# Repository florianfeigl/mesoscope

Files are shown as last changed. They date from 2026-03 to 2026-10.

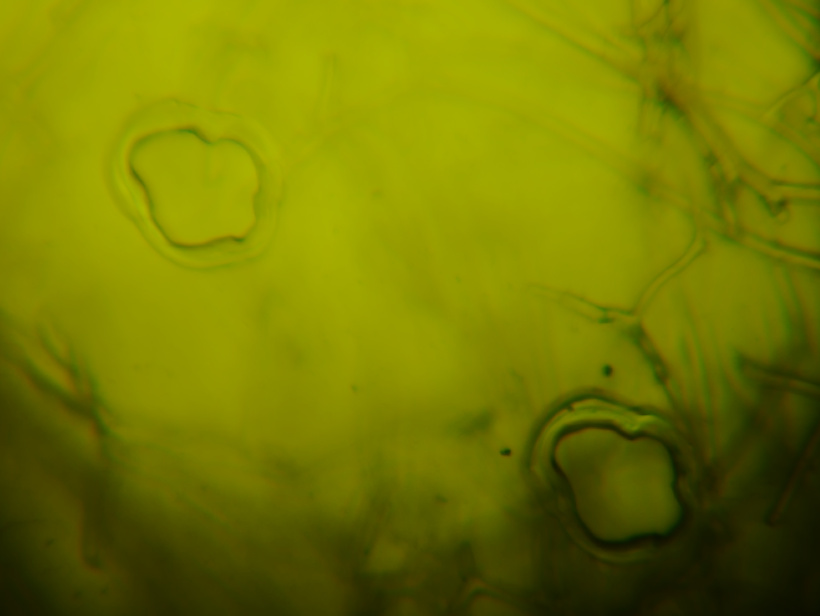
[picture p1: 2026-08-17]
resources/OFM_2026-08-17T13_33_07.449Z.jpeg

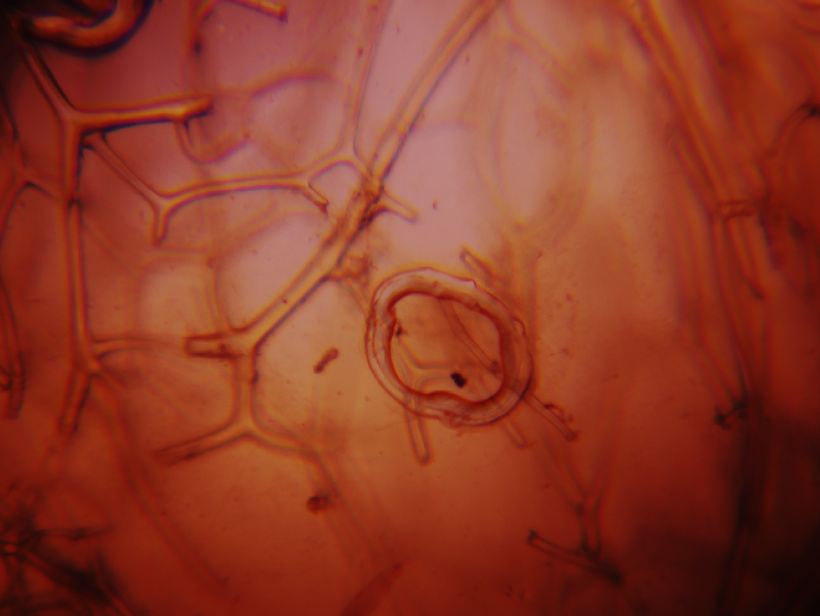
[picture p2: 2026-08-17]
resources/OFM_2026-08-17T14_42_57.477Z.jpeg

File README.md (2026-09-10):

# Mesoscope — IDANA

**IDANA** is the mesoscope model built in this project: an automated cell-imaging
microscope (Raspberry Pi 5 + Hailo-8 NPU + HQ Camera, OpenFlexure stack).
*Formerly "CELLAIR".*

## Roadmap

### Phase 1: Infrastructure & Base Setup
- [x] **Hardware Setup (Raspberry Pi 5)**
    - [x] Install Raspberry Pi OS (Trixie, Python 3.13)
    - [x] Configure AI HAT (26 TOPS) drivers and dependencies
    - [x] Configure Pi HQ Camera (IMX477) integration
    - [ ] Configure RTC Module (DS3231) -- hardware not yet connected
- [x] **Ansible Configuration**
    - [x] Create Ansible Playbook/Role for base system setup
    - [x] Create Ansible Role for AI HAT & Camera (`rpicam-apps`, `hailo-all`, `python3-picamera2`)
    - [x] Create Ansible Role for OpenFlexure dependencies

### Phase 2: Application Layer (OpenFlexure Porting)
- [x] Port OpenFlexure Server (v3, 3.0.0-alpha4) to RPi5/Trixie (Python 3.13)
    - [x] Switch from legacy `master` branch (Python 3.7/Flask) to `v3` branch (Python >= 3.11/FastAPI)
    - [x] Resolve build dependencies (`libcap-dev`, `rpicam-apps` replacing `libcamera-apps`)
    - [x] Deploy configuration (`ofm_config.json`) with HQ Camera and DummyStage
    - [x] Download and integrate web app frontend from GitLab CI artifacts
    - [x] Verify server starts, web UI accessible on port 5000
- [x] Fix Pi 5 pisp ISP compatibility (vc4 tuning files incompatible with Pi 5 ISP)
- [x] Fix pipewire camera device conflict (pipewire holds /dev/media* preventing picamera2 access)
- [x] Fix systemd SupplementaryGroups for camera access (video, render)
- [x] Fix DKMS kernel module build ordering (reboot between apt upgrade and modprobe)
- [x] Fix camera black frame issue (manual exposure via API: 20 ms / gain 1.5 / colour gains 1.4,2.3)
- [ ] Create software list for OpenFlexure Suite
- [ ] Validate Autofocus with motorised stage

### Phase 3: HQ Camera (IMX477) Integration
> **Note:** The primary microscope camera is the Pi HQ Camera (IMX477, C-mount).
> OpenFlexure v3 supports the IMX477 natively via picamera2. A custom optics module
> with a 125-150mm tube lens is required to properly fill the larger IMX477 sensor
> (see `hardware/optics/OPTICS_MODULE.md`).

- [x] Deploy OpenFlexure with HQ Camera (IMX477) configuration
- [x] Test live preview via OpenFlexure web UI
- [x] Verify Hailo-8 NPU inference (see test results below)
- [x] Design and 3D-print custom optics module for IMX477 + 125-150mm tube lens (STLs generated)
- [ ] Assemble optics module with tube lens and IMX477
- [ ] Validate autofocus with motorised stage

### Phase 4: Integration Testing
- [x] **Hardware Verification**
    - [x] Hailo-8 AI Processor detected on PCIe (`lspci`)
    - [x] Pi HQ Camera (IMX477) detected: 4056x3040 @10fps / 2028x1520 @30fps
    - [x] I2C buses operational (bus 1, 6, 10, 13, 14)
    - [x] Hostname, timezone, NTP synchronization confirmed
- [x] **OpenFlexure Server**
    - [x] Server starts and responds on HTTP (port 5000)
    - [x] Web UI accessible
    - [x] HQ Camera (IMX477) initialised and streaming
    - [x] Fix camera black frame issue (manual exposure via API: 20 ms / gain 1.5 / colour gains 1.4,2.3)
    - [ ] Test stage control via sangaboard (if connected)
    - [ ] Verify smart scan and autofocus functionality
- [x] **AI Inference (Hailo-8 NPU)**
    - [x] Hailo-8 NPU firmware verified: v4.23.0, Hailo-8 architecture
    - [x] DKMS driver build automated in Ansible (`hailo_pci` kernel module)
    - [x] Hailo-8 NPU inference verified (YOLOv8s Pose, 91.5 inf/s, 10.9ms latency)
    - [x] Benchmark complete (see Inference Test Results section)
- [x] **System Stability (post-reboot verification 2026-03-04)**
    - [x] RTC (DS3231) keeps time across reboots (`hwclock -r` confirmed)
    - [x] Hailo PCIe driver loads automatically on boot (`hailo_pci` module, `/dev/hailo0`)
    - [x] OpenFlexure service starts on boot, camera streaming active
    - [x] HQ Camera (IMX477) detected after reboot
    - [x] Resource usage under load (see below)

#### Resource Profile (idle with camera streaming)
| Resource | Value |
|---|---|
| CPU | 4 cores, load avg 0.71 (OpenFlexure ~63% of one core) |
| RAM | 762 MB used / 15 GB total (5% utilisation) |
| Temperature | 48.3C |
| Disk | 11 GB used / 117 GB total (10%) |
| Swap | 0 B used |

### Phase 5: OpenFlexure Microscope Build

> **Optics design:** See [`hardware/optics/OPTICS_MODULE.md`](hardware/optics/OPTICS_MODULE.md)
> for the full optical calculation — tube lens selection, sensor-to-lens distance,
> C-mount offset, and printed module dimensions for the IMX477 + scraped ≤10x objective.

- [ ] **Hardware Procurement**
    - [x] Pi HQ Camera (IMX477, C-mount) -- acquired, currently mounted on conventional microscope
    - [x] Scraped objective ≤10x (finite conjugate 160 mm) -- sourced from existing microscopes
    - [x] Tube lens 125 mm + 150 mm achromatic doublet (12.7mm dia) — acquired 2026-06-20
    - [ ] Sangaboard v0.5 motor controller
    - [ ] 3x 28BYJ-48 stepper motors -- acquired
- [ ] **3D Printing**
    - [x] Verify objective type (160 mm finite conjugate) and parfocal distance (see OPTICS_MODULE.md)
    - [x] Clone OpenFlexure repo (`hq_camera` branch) and set `CAMERA = "picamera_hq"` + tube lens params
    - [x] Generate custom optics module STLs with OpenSCAD (125mm and 150mm variants)
    - [ ] Print all parts (see `hardware/PRINT_CHECKLIST.md`)
    - [ ] Assemble optics module with tube lens and IMX477
- [ ] **Assembly & Calibration**
    - [ ] Assemble OpenFlexure with HQ Camera + scraped objective
    - [ ] Integrate with Ansible-deployed software stack
    - [ ] Calibrate flat-field correction and lens shading
    - [ ] Test motorised stage control via OpenFlexure web UI

## Bill of Materials

### Computing & AI
| Component | Description | Est. Price | Status |
|---|---|---|---|
| Raspberry Pi 5 (8GB) | Main computing unit | ~80 EUR | Acquired |
| AI HAT+ (Hailo-8, 26 TOPS) | PCIe NPU for heavy inference (segmentation, YOLOv8) | ~70 EUR | Acquired |
| DS3231 RTC Module | Battery-backed real-time clock | ~5 EUR | Acquired |
| GPIO Stacking Header | Pass-through for RTC under AI HAT | ~3 EUR | Acquired |
| MicroSD Card (32GB+) | OS and software storage | ~10 EUR | Acquired |
| USB-C Power Supply (27W) | Official RPi5 PSU | ~15 EUR | Acquired |

### Optics & Microscopy
| Component | Description | Est. Price | Status |
|---|---|---|---|
| Pi HQ Camera (IMX477) | C-mount, 12.3 MP sensor -- **primary microscopy camera** | ~35 EUR | Acquired |
| Scraped ≤10x objective | Finite conjugate 160 mm, sourced from existing microscopes | ~0 EUR | Acquired |
| Tube lens (125 mm + 150 mm) | Achromatic doublet, 12.7 mm dia | ~15-80 EUR | **Acquired** |
| 20x RMS Plan Achromat (0.40 NA) | Cell tracking, movement patterns (~0.7 µm resolution) | ~25-80 EUR | Pending |
| 40x RMS Plan Achromat (0.65 NA) | Subcellular detail, calcification (optional) | ~25-80 EUR | Optional |

### Motorised Stage
| Component | Description | Est. Price | Status |
|---|---|---|---|
| Arduino Nano (ATmega328p) | Sangaboard-compatible controller (DIY workaround) | ~5 EUR | Pending |
| 3x ULN2003 Driver Boards | Unipolar stepper drivers (usually bundled with motors) | ~3 EUR | Pending |
| 3x 28BYJ-48 Stepper Motors | 5V unipolar geared steppers (OpenFlexure standard) | ~5 EUR | Acquired |
| Jumper Wires (19x) | Wiring between Nano and ULN2003 boards | ~3 EUR | Pending |
| USB Cable (Mini-B) | Power + serial between RPi5 and Arduino Nano | ~3 EUR | Pending |

> **Alternative:** Sangaboard v0.3 PCB (~30-40 EUR if available from OpenFlexure vendors).
> The DIY workaround uses the same firmware and is fully compatible.

### 3D Printed Parts
| Component | Description | Est. Price | Status |
|---|---|---|---|
| OpenFlexure Microscope Body | Main structure with flexure stage | ~5 EUR filament | Ready to print |
| Optics Module (HQ Camera, 150mm) | Holds objective + HQ Camera + 150mm tube lens | ~2 EUR filament | STL generated |
| Optics Module (HQ Camera, 125mm) | Holds objective + HQ Camera + 125mm tube lens | ~2 EUR filament | STL generated |
| Illumination Module | LED illumination (transmission) | ~2 EUR filament | Ready to print |

### Consumables & Misc
| Component | Description | Est. Price | Status |
|---|---|---|---|
| M3 Screws/Nuts (assorted) | Assembly hardware | ~5 EUR | Pending |
| LED + Resistor | Sample illumination | ~2 EUR | Pending |
| Viton O-rings | Flexure preload (check OpenFlexure BOM) | ~3 EUR | Pending |

> **Estimated total (remaining):** ~110-170 EUR (depending on objective choice)

### Phase 6: Research & Experimentation
- [ ] **Incubator Setup (37C)**
    - [ ] Design separation of computing unit (outside) and camera (inside)
    - [ ] Inverted geometry: objective below, sample on top (OpenFlexure default)
- [ ] **Experiments**
    - [ ] Acquire PFA-fixed chip preparations
    - [ ] Analyze significant movement pattern changes in cells during calcification
    - [ ] Investigate influence of pressure changes on calcification [in progress]
    - [ ] Test series: Test different medium flow rates [in progress]

## System Architecture

```
                              MESOSCOPE SYSTEM
═══════════════════════════════════════════════════════════════════════════════

                    ┌─────────────────────────────────────┐
                    │         Raspberry Pi 5 (8GB)        │
                    │   ┌─────────────┐  ┌─────────────┐  │
                    │   │  OFM Server │  │ AI HAT+     │  │
                    │   │   (FastAPI) │  │ Hailo-8     │  │
                    │   └─────────────┘  │ 26 TOPS     │  │
                    │                    └─────────────┘  │
                    └──────────────┬──────────────────────┘
                                   │ CSI
                    ┌──────────────▼──────────────────────┐
                    │      HQ Camera (IMX477, 12MP)       │
                    │      C-Mount │ 150mm Achromat       │
                    │      10x/0.25 Objektiv              │
                    └──────────────┬──────────────────────┘
                                   │
                    ┌──────────────▼──────────────────────┐
                    │     OpenFlexure Microscope Body     │
                    │     Sangaboard v5 + 3× 28BYJ-48    │
                    │     XYZ-Flexure Stage               │
                    └──────────────┬──────────────────────┘
                                   │
                                   │  montiert auf Schlitten
                                   │
═══════════════════════╤═══════════▼══════╤══════════════════════════════════
  Linearschiene        │                  │
  ═════════════════════╪══════════════════╪═════════════════════════════════▶
                        │     ← →         │
                   Antrieb/Motor          │
═══════════════════════╧══════════════════╧══════════════════════════════════
          │                    │                    │
          ▼                    ▼                    ▼
   ┌─────────────┐      ┌─────────────┐      ┌─────────────┐
   │             │      │             │      │             │
   │ {Bioreaktor}│      │ {Bioreaktor}│      │ {Bioreaktor}│
   │             │      │             │      │             │
   │  hFOB 1.19  │      │  hFOB 1.19  │      │  hMEC 1    │
   │  + hMEC 1   │      │  + hMEC 1   │      │  (Kontrolle)│
   │             │      │             │      │             │
   └─────────────┘      └─────────────┘      └─────────────┘
         #1                   #2                   #n
```

Das Mikroskop fährt automatisch entlang der Schiene von Bioreaktor zu Bioreaktor,
nimmt Bilder auf, und der Hailo-8 läuft on-device Inferenz (Zellzählung,
Konfluenz, Segmentierung) — ohne externe Recheninfrastruktur.

> **Nächster Meilenstein — Halterung/Schiene:** Der mechanische Aufbau (Mikroskop
> um 90° gekippt auf X-Linearschiene + Reaktor-Gerüst in Serie) ist als Konzept in
> [`docs/RAIL_MOUNT_CONCEPT.md`](docs/RAIL_MOUNT_CONCEPT.md) festgehalten
> (Geometrie, Schienen-/Antriebsempfehlung, Flexure-Schwerkraftrisiko, offene Punkte).

### HQ Camera (IMX477) -- Microscopy

The Pi HQ Camera with C-mount and RMS objectives provides cell-level resolution:

| Objective | Resolution | Use Case |
|---|---|---|
| ≤10x / ≤0.25 NA | ~1.3 µm | Overview, colony counting |
| 20x / 0.40 NA | ~0.7 µm | Cell tracking, movement patterns |
| 40x / 0.65 NA | ~0.4 µm | Subcellular detail, calcification |

The custom 125-150mm tube lens (vs. standard 50mm) fills the larger IMX477 sensor
(7.86×5.89 mm vs. 3.68×2.76 mm for Pi Camera v2), achieving ~85-95% sensor utilization.
See [`hardware/optics/OPTICS_MODULE.md`](hardware/optics/OPTICS_MODULE.md) for details.

### Hailo-8 NPU -- Inference

The Hailo-8 AI HAT runs compiled HEF models for real-time cell segmentation at the microscope:

- **YOLOv8s-seg**: Cell segmentation (osteoblast, epithelial, calcium classes)
- **ByteTrack**: Cell tracking for migration velocity and calcium proximity analysis
- **Throughput**: 91.5 inf/s at 10.9ms latency (YOLOv8s Pose benchmark)

## Post-Deployment Verification

Run the following after a fresh boot to verify all subsystems:

```bash
# System basics
hostname && timedatectl

# RTC
sudo hwclock -r

# I2C - RTC at 0x68
sudo i2cdetect -y 1

# Hailo NPU
lsmod | grep hailo
ls /dev/hailo*
hailortcli fw-control identify

# Camera (HQ Camera IMX477)
rpicam-hello --list-cameras

# OpenFlexure
sudo systemctl status openflexure

# HTTP
curl -s http://localhost:5000/ | head -5
```

### Expected Results
| Check | Expected |
|---|---|
| Hostname | `mesoscope` |
| Timezone | `Europe/Berlin`, NTP synced |
| RTC | Current time, matches system clock |
| I2C bus 1 | `UU` at address `0x68` (DS3231) |
| Hailo module | `hailo_pci` loaded, `/dev/hailo0` present |
| Hailo firmware | v4.23.0, Hailo-8 architecture |
| Camera | `imx477` detected, 4056x3040 / 2028x1520 |
| OpenFlexure | `active (running)`, enabled on boot |
| HTTP | HTML response on port 5000 |

## Deployment

### Prerequisites (Client Side)
- **Ansible** (>= 2.10)
- **Python 3**
- **SSH Client** (e.g., OpenSSH)
- **Git**

### Target System Defaults
| Component | Value |
|---|---|
| Hostname | `mesoscope` |
| Provision User  | `lab` |
| OS | Raspberry Pi OS (Trixie) |
| Python | 3.13 |
| Hardware | RPi5, AI HAT 26 TOPS, HQ Camera IMX477 |

### Step 1: Flash the SD Card
1. Download and install [Raspberry Pi Imager](https://www.raspberrypi.com/software/).
2. Select **Raspberry Pi OS (64-bit, Trixie)** as the operating system.
3. Click the **settings icon** (gear) and configure:
   - **Hostname:** `mesoscope`
   - **Username:** `lab`
   - **Password:** (choose a secure password)
   - **Enable SSH:** select "Allow public-key authentication only" and paste your public key (e.g., contents of `~/.ssh/id_ed25519.pub`)
   - **Timezone:** `Europe/Berlin`
   - **WiFi:** configure if not using Ethernet
4. Flash the SD card and insert it into the Raspberry Pi 5.

### Step 2: Verify SSH Connection
After the Pi has booted (allow ~1-2 minutes for first boot):
```bash
ssh lab@mesoscope.local
```

### Step 3: Run the Ansible Playbook
```bash
git clone git@github.com:florianfeigl/mesoscope.git
cd mesoscope/ansible
ansible-playbook site.yml --skip-tags motor-controller -v -K
```

> **Note:** The `motor-controller` tag is skipped until Sangaboard hardware is connected.
> The playbook includes Pi 5 compatibility patches (pisp ISP tuning, pipewire masking, etc.)
> applied automatically via the `patch_rpi5_pisp.sh` script.

### Step 4: Verify
Access OpenFlexure at `http://mesoscope.local:5000/`

### Customization
To use different credentials, update the following files:
- `ansible/inventory/hosts.yml` -- hostname, IP, and SSH user
- `ansible/group_vars/all.yml` -- hostname and application user
- `ansible/ansible.cfg` -- default remote user

## AI Models

### Hailo-8 NPU Models

Pre-installed HEF models at `/usr/share/hailo-models/` (installed via `hailo-models`).
These run on the Hailo-8 NPU (AI HAT, 26 TOPS) via PCIe for real-time cell analysis.

| Model | Task | File |
|---|---|---|
| YOLOv8s Pose | Pose Estimation | `yolov8s_pose_h8.hef` |
| YOLOv5n Segmentation | Segmentation | `yolov5n_seg_h8.hef` |
| YOLOv5s PersonFace | Detection | `yolov5s_personface_h8l.hef` |
| SCRFD 2.5G | Face Detection | `scrfd_2.5g_h8l.hef` |

> See `ls /usr/share/hailo-models/` for the full list (18 models).
> The custom cellseg model (YOLOv8s-seg fine-tuned on osteoblast/epithelial/calcium classes)
> will be compiled to HEF and deployed at `model/models/compiled/cellseg.hef`.

## Inference Test Results

### Hailo-8 NPU via PCIe (tested 2026-03-03)
```
Firmware: v4.23.0 (release, app, extended context switch buffer)
Device: /dev/hailo0 on PCIe bus 0001:01:00.0
Model: YOLOv8s Pose (yolov8s_pose_h8.hef)
Input: 640x640x3
Output: 9 tensors (multi-scale detection + keypoints)
Throughput: 91.5 inferences/sec
Latency: 10.9ms avg
```

### Architecture
```
HQ Camera (IMX477) --> picamera2 streams (OpenFlexure UI)
                         |
                         v
Captured Frame --> Hailo-8 NPU (PCIe, 26 TOPS) --> Output tensors
                    Heavy: segmentation, pose estimation, custom HEF models
## Notes
- **Meetings:** Jour fixe is usually Tuesday 10:00 AM.

### Suppliers
- Praxisdienst: [https://www.praxisdienst.com/de-de]
- FluidControl: [https://www.fluidcontrolproducts.com/]

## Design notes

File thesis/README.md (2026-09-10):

# Mesoscope — Master's Thesis (LaTeX)

IEEEtran journal-class draft of the mesoscope thesis. The scaffold and the
already-known content (introduction, background, requirements, optical,
mechanical, electronics, software, edge-AI, cost) are filled in; results that
depend on future experiments are marked inline as `[TODO: ...]` (red).

## Layout

| Path | Contents |
|---|---|
| `main.tex` | Preamble, title, abstract, `\input`s all sections, bibliography |
| `sections/01_introduction.tex` … `11_conclusion.tex` | Body chapters |
| `sections/A_appendix.tex` | Printed-parts table and wiring appendix |
| `references.bib` | BibTeX entries (OpenFlexure, UC2, Squid, Cellpose, StarDist) |
| `figures/` | Local figures (currently empty) |

Figures are also pulled from `../hardware/assembly/` via `\graphicspath`. The
exploded-view PNGs there are **not committed** — regenerate them first with
`hardware/assembly/build_exploded.sh` (the thesis uses
`exploded_view_nolabels.png`).

## Build

```bash
make            # pdflatex + bibtex + pdflatex x2  ->  main.pdf
make clean      # remove aux files
make distclean  # also remove main.pdf
```

Requires `pdflatex` and `bibtex` (TeX Live; `texlive-publishers` provides
`IEEEtran.cls`/`IEEEtran.bst`). `biber` is **not** needed. `latexmk` is
optional (`make watch`).

## Status

Draft (milestone M0). Open decisions and parameter gaps are flagged as
`[TODO: ...]` and cross-referenced to `docs/THESIS_PARAMETER_GAPS.md` and the
milestones M1–M3.

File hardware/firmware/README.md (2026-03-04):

# Motor Controller Firmware

This directory contains the Sangaboard-compatible firmware for the Arduino Nano motor controller.

The firmware is automatically deployed via the `motor-controller` Ansible role.

**Source:** https://gitlab.com/openflexure/sangaboard/

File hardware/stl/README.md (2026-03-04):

# OpenFlexure Microscope STL Files

Download the STL files from the OpenFlexure v7 build server and place them in the appropriate subdirectories.

**Source:** https://build.openflexure.org/openflexure-microscope/v7.0.0-beta2/docs/high_res_microscope.html

## Directory Structure

```
stl/
  microscope-body/    Main body with flexure stage
  optics-module/      Camera + objective holder (HQ Camera variant)
  stage/              Sample stage and clips
  illumination/       LED illumination module and condenser
  motor-mounts/       Stepper motor mounting brackets
  tools/              Assembly jigs and alignment tools
```

## Print Settings (recommended)
- **Material:** PLA or PETG
- **Layer height:** 0.15-0.2mm
- **Infill:** 20-30%
- **Supports:** As indicated per part in OpenFlexure instructions
- **Nozzle:** 0.4mm

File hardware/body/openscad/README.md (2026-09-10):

# Mesoscope main body (Z-focus only)

OpenSCAD override of the OpenFlexure `main_body` for the rail mount
(`docs/RAIL_MOUNT_CONCEPT.md`). In the tilted setup the sample chips hang
externally from the bridge, so the microscope's own X/Y stage is never used.
This variant removes it.

## Files

| File | Purpose |
|---|---|
| `main_body_original.scad` | Byte-identical backup of upstream `openscad/main_body.scad` (hq_camera branch, commit `5e90e97`). |
| `main_body_structure_original.scad` | Byte-identical backup of upstream `openscad/libs/main_body_structure.scad`. |
| `main_body_mesoscope.scad` | Entry file (copied over `openscad/main_body.scad`). `VERSION_STRING = "Mesoscope"`. |
| `main_body_structure_mesoscope.scad` | Upstream structure lib + a mesoscope `main_body()` at the bottom. All upstream modules are kept unchanged so the rendering scenes still work. |
| `build_body.sh` | Copies the overrides into the upstream clone and renders. |

## What was removed vs. upstream

- `xy_stage_with_nut_traps` — the sample stage (Tisch) incl. nut traps
- `xy_legs_and_actuators` — the four flexure legs, both X/Y actuator columns and their screw seats / motor lugs
- `xy_flexures`, `xy_leg_ties` — flexures and print ties
- `side_housing` — the two X/Y motor cable housings on the outer walls
- `xy_actuator_cut_outs` — no columns left to clear from the walls

## What is kept

- `complete_z_actuator` + `z_axis_casing` (focus, optics module mount, condenser/illumination dovetail mount)
- `internal_xy_structure` — inner wall + base with the central optics cut-out and the reflection-illuminator cut-out
- outer walls (`wall_inside/outside_xy_actuators`, `wall_between_actuators`) — where the actuator columns stood, a short straight wall segment (`mesoscope_actuator_stub_wall`) closes the gap
- `mounting_hole_lugs` — the four M3 base lugs (needed later for the rail carriage adapter)
- logos / version string on the outer walls

Removing the X/Y flexures also removes the X/Y gravity-sag risk of the tilted
microscope (RAIL_MOUNT_CONCEPT §5); only the Z flexure remains.

## Build

```bash
hardware/body/openscad/build_body.sh            # -> hardware/stl/models/main_body_mesoscope.stl
hardware/body/openscad/build_body.sh original   # -> hardware/stl/models/main_body_original.stl
hardware/body/openscad/build_body.sh all
```

Needs the upstream clone at `sources/openflexure-microscope` (same location
as `build_stand.sh`). After the run the upstream clone is left in the
*mesoscope* state, so `rendering/librender/rendered_main_body.scad` and the
full-microscope scenes (`hardware/mount/openscad/complete_microscope_*.scad`)
render the reduced body once `rendered_main_body.stl` is regenerated.

## Open points

- The Sangaboard stays for now (decision 2026-09-03); X/Y motor outputs are
  simply unused. `ofm_config.json.j2` still declares a 3-axis stage — OK for
  now, the X/Y axes just have nothing attached.
- Test print pending. Check that the stub walls and the front lugs print
  cleanly without the actuator columns behind them.

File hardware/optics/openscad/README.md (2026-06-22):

# Mesoscope HQ Camera Optics Module — OpenSCAD Sources

Custom OpenSCAD configurations for the Pi HQ Camera (IMX477) with extended tube
lens options (125mm and 150mm achromatic doublets).

## Files

| File | Purpose |
|---|---|
| `optics_configurations_hq.scad` | Tube lens configs: 125mm and 150mm |
| `rms_optics_module_hq.scad` | Main module with dispatch for all 6 optics types |
| `picamera_hq_cmount.scad` | **C-mount override** for upstream `picamera_hq.scad` — replaces bare-PCB mounting with a C-mount flange seat |
| `build_optics.sh` | Copies configs into upstream repo and builds STLs |

## Setup

```bash
# 1. Clone upstream repo (once):
cd ~/dev/mesoscope/sources
git clone --branch hq_camera --single-branch \
  https://gitlab.com/openflexure/openflexure-microscope.git
cd openflexure-microscope && git lfs install && git lfs pull

# 2. Build (the script copies custom files into the upstream repo automatically):
cd ~/dev/mesoscope/hardware/optics/openscad
./build_optics.sh
```

If the upstream repo is re-cloned, just re-run `./build_optics.sh` — it copies the custom files each time.

## Building STLs

```bash
./build_optics.sh          # Both configurations
./build_optics.sh 125      # 125mm only
./build_optics.sh 150      # 150mm only
```

Output: `../stl/models/optics_hq_125_rms.stl` and `optics_hq_150_rms.stl`

## Available Optics Configurations

| OPTICS name | Tube lens | f (mm) | ffd (mm) | Conjugate | Camera |
|---|---|---|---|---|---|
| `rms_f125d13` | 125mm | 125 | 122.6 | Finite | picamera_hq |
| `rms_f150d13` | 150mm | 150 | 146.9 | Finite | picamera_hq |
| `rms_infinity_f125d13` | 125mm | 125 | 122.6 | Infinity | picamera_hq |
| `rms_infinity_f150d13` | 150mm | 150 | 146.9 | Infinity | picamera_hq |

## Key Parameters (from OPTICS_MODULE.md)

| Parameter | 125mm | 150mm |
|---|---|---|
| Magnification (M) | 0.469 | 0.515 |
| Effective FN | 20.9 mm | 19.0 mm |
| Sensor fill | ~85% | ~95% |
| Lens-to-sensor (q) | 66.4 mm | 72.8 mm |

Use **150mm** for <=10x objectives (preferred).
Use **125mm** for <=4x objectives or wider field of view.

## Verifying tube_lens_ffd

Before printing, check your lens datasheet for the **back focal distance (BFD)**.
If it differs from the values below, edit `optics_configurations_hq.scad`:

| Lens | ffd | Source | Parameter |
|---|-----|---|---|
| 125mm | 124.1 mm | taulab supplier (Filip, 2026-06-22) | `rms_f125d13_config` |
| 150mm | 148.8 mm | taulab supplier (Filip, 2026-06-22) | `rms_f150d13_config` |

## C-mount camera-side interface

The mesoscope uses the Pi HQ Camera **intact** (with its C-mount body), not the
bare PCB. `picamera_hq_cmount.scad` overrides the upstream `picamera_hq.scad` so:

| Parameter | Upstream (bare PCB) | Mesoscope (C-mount) |
|---|---|---|
| `mount_height` | 4.5 mm | 17.526 mm (C-mount FFD) |
| `sensor_height` | 1 mm | 0 mm (referenced to flange face) |
| Camera mount | 4× M2 posts on a 30 mm pattern | Smooth bore + 32 mm flange seat |
| Camera screws | 4× No.2 self-tapping | None — not needed with C-mount |
| Cover STL | `picamera_hq_cover.stl` | None — camera body is its own enclosure |

The optics module has a **32.6 mm bore × 4 mm deep flange seat**; the
C-mount housing of the HQ Camera (32 mm OD) slides into it with ~0.3 mm
clearance. Above the seat, a **26 mm clear bore** lets the sensor see the tube
lens unobstructed. The sensor ends up exactly 17.526 mm below the printed seat
face — matching the C-mount standard.

We deliberately do **not** print 1"-32 UN female threads (FDM threads are
unreliable at this scale). The slip-fit is more than tight enough for an
inverted scope where the C-mount face seats against the printed lip under
gravity. If you mount the scope upright, add a small printed retainer or a
wrap of PTFE tape on the camera flange.

## Implementation note: sequential_hull fix

The OpenFlexure upstream `optics_module_rms()` uses `sequential_hull()` to build
the module body. This hull always **closes the underside** — regardless of what
`picamera_hq_camera_mount` subtracts internally. The C-mount opening is therefore
cut as a post-process in `rms_optics_module_hq.scad` via an explicit `difference()`
in `optics_module_rms_cmount()`:

- Flange seat (⌀32.6 mm, 4 mm deep) cut from `camera_mount_top_z` downward
- Clear optical bore (⌀26 mm) cut through the full remaining hull depth

`rms_camera_mount_top_z()` is `-33.8 mm` for the 150 mm config (computed from
sensor Z + C-mount FFD). The safety cutout extends 40 mm further down to punch
through any hull-generated floor.

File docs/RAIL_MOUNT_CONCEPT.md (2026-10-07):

# Rail Mount Concept — Tilted Microscope on Linear X-Rail

> **Status:** Concept + first schematic CAD draft (updated 2026-09-03 —
> motor-control architecture is now a **hybrid**: the Sangaboard stays for
> focus + illumination LED, the linear rail runs on a standalone TMC2209 at
> GPIO; this narrows the earlier 2026-09-02 "all-Python GPIO stage" to just the
> rail axis. See the decision box in §7.1; handoff list at the end of §8).
> Next milestone: the mount ("Halterung") that lays the mesoscope on its side
> and carries it along a linear X-rail past a series of bioreactors.
>
> **Schematic massing draft:** `hardware/mount/openscad/rail_mount_mesoscope.scad`
> (parametric block model — shared **base plate (Grundplatte)**, the rail beam +
> MGN12 guide under the moving microscope, NEMA17 + T8 leadscrew drive, and a
> **reactor bridge (Brücke)**: a continuous traverse board with per-station
> cutouts from which the chips hang **hochkant**). Previews:
> `rail_mount_preview.png` (3/4 from the objective side) and
> `rail_mount_top.png` (3/4 from the light-source side, full row). This is a
> massing model to make the layout discussable, **not** print-ready geometry.
>
> ✅ **Full mesoscope model embedded — registration CORRECTED (2026-08-25):**
> the real assembled geometry is `import()`ed into the draft
> (`real_model = true`) from `hardware/stl/models/complete_microscope_rms.stl`.
> The upstream render applies `rotate([-90,0,0])`, so in the STL the optical
> axis is the line `x=0, z=0` pointing **+Y** (objective toward the reactors).
> **Important correction:** the render scene includes the **stand**, which
> raises the microscope body frame by **75 mm** (`microscope_on_stand_pos`:
> lug_z 55 + lug 20). The sample plane therefore sits at **model y = 150**,
> *not* at `sample_z = 75` as previously assumed — that wrong registration
> placed the chip 75 mm *inside* the microscope and caused both rounds of
> visible clipping. Measured from the STL: **objective tip = y 146.65**
> (global foremost point, working distance 3.35 mm), condenser tip = y 167.5
> (17.5 mm above the sample plane — the earlier "2.5 mm" figure was an
> artifact of the wrong registration).
>
> ✅ **Illumination arm removed from the model (per decision):** the 16 mm chip
> would leave only ~1.5 mm nominal clearance under the stock condenser, and
> the illumination must be redesigned anyway for trans-illumination from
> behind the chip row. The model is now rendered **without sample clips AND
> without the illumination assembly** (dovetail, condenser, wiring):
> `hardware/mount/openscad/complete_microscope_rms_noclips_noillum.scad`, a
> variant of upstream `rendering/complete_microscope.scad` that re-composes
> `assembled_microscope_without_electronics` as motors +
> `mounted_microscope()` only. Copy into the upstream `rendering/` dir and
> render there to regenerate the STL. The custom light source ("Halterung
> unten") comes later as a separate part on the +Y side behind the chips.
>
> ✅ **10 mm working gap established (per decision):** the microscope is shifted
> back along the optical axis (`model_dy = (75 − 10) − 146.65 ≈ −81.7 mm`)
> so the objective tip stops **10 mm** before the chip window (world y = 65
> vs. window at y = 75). Since the tip is the model's foremost point, the
> **entire microscope stays at world y ≤ 65 at every rail position** —
> chips (y ≥ 75), traverse board (y ≥ 80) and pillars are cleared by
> construction; no separate travel-path check needed. **Optics consequence:**
> the stock focus plane lies 3.35 mm beyond the tip, so to focus at the chip
> window inner face the objective must protrude **~8 mm beyond stock** —
> more to reach deeper planes inside the 16 mm chip. This optics-module
> adaptation (longer nose/extension tube) is an accepted follow-up task.
>
> ✅ **Bridge clearance:** with the shifted microscope (everything ≤ y 65) the
> slim traverse board (24 mm, starting at y = 80, `bridge_y_clear = 5`) is
> trivially clear. The station cutouts are **front-open notches**: chips
> slide in from the objective side.
>
> ✅ **Bioreactor STL integrated:** `hardware/bioreactors/chip_senkrecht_mit_bodenplatte.stl`.
> Base plate (Bodenplatte) removed for the calculations per
> instruction → chip body **70 × 40 × 16 mm**, optical window **18 × 8 mm**,
> 4 fluidic ports. Only the **series pitch** (reactor-to-reactor spacing along
> X) is still an assumption (80 mm) to confirm.
>
> ✅ **Hochkant + Brücke (2026-08-25):** the chips are now mounted **upright
> (hochkant)** and **hang from a bridge** — a continuous traverse board
> ("schmales Brett" in chip dimensions) with per-station cutouts
> (Aussparungen), carried by two end pillars on the Grundplatte. Imaging goes
> horizontally **through the 16 mm chip thickness**: light source on the +Y
> side → chip → objective on the −Y side. The fluidic ports + tubes
> (Schläuche) exit at the **top** — that is why top access is impossible and
> the chips must hang, keeping the space **below** free for the moving
> mesoscope. Pillar clearance at the end stops is confirmed: microscope
> half-width 85 mm vs. `bridge_x_clear = 120 mm` → ≥ 35 mm margin; the
> travel path under the hanging row is clear (microscope ≤ y 65 everywhere).

This document captures the geometry, the mechanical concept, open decisions, and
the reasoning behind them, so the next session can start from a shared picture.

---

## 1. Goal

Transform the microscope from a static inverted instrument into a **moving
imaging head** that scans a **row of bioreactors** arranged in series:

- Lay the whole OpenFlexure microscope on its side (**90° tilt**), resting on the
  face of the **Z-axis motor**, so the **optical axis becomes horizontal**.
- Bind a **linear rail under the microscope** so it rides on a **carriage** in
  **X** (90° to the optical path) — **only the microscope moves.**
- On the **same base plate (Grundplatte)**, a **fixed bridge (Brücke)** holds the
  **bioreactors in a stationary row** at a working-distance offset along the
  optical axis. The reactors do **not** move with the carriage.
- A **separate stepper drive** moves the microscope carriage in X so it travels
  **along the fixed row of reactors**; at each station it images the sample.

This matches the system architecture diagram in the root `README.md`
("montiert auf Schlitten" / "Linearschiene" / "Antrieb/Motor" / Bioreaktoren #1…#n).

---

## 2. Coordinate transformation (90° tilt)

**Before (current, inverted OpenFlexure):**
- Optical axis = Flexure **Z**, **vertical**. Objective below the sample.
- Gravity acts **along** the optical axis (Z) — the stage is designed for this.

**After (tilted onto the Z-motor face):**

| World axis | Direction | Role |
|---|---|---|
| World **Y** | horizontal, toward the reactors | optical axis = old Flexure **Z** (focus) |
| World **X** | horizontal, along the rail | scan direction (separate stepper drive) |
| World **Z** | vertical (gravity) | now **perpendicular** to the optical axis |

**Consequence for focus (good):** the old Flexure-Z (focus travel) is now
horizontal and points at the reactor → **autofocus/focus still works.**
Flexure-Z moves the **optics module**, which is part of the microscope — it
works regardless of where the sample sits.

**Consequence for framing (important insight, 2026-09-02):** the Flexure
**X/Y axes move the sample stage platform** — but the chips hang externally
from the bridge, **not** on the microscope's stage. In the tilted setup the
X/Y flexures are therefore **functionless** for framing. Fine positioning is
instead:
- **horizontal (world X):** the rail drive itself — Tr8×2 gives
  0.01 mm/microstep, precise enough for fine framing, not just station hops;
- **vertical (world Z):** open — baseline is a one-time manual height
  adjustment; a motorized lift stage is a documented expansion option (§7.1a).

> TODO (fresh session): verify against the upstream OpenFlexure CAD which
> flexure axes move the stage platform vs. the optics module, to confirm this
> mapping before mechanical design.

**Consequence for gravity (risk — see §5):** gravity is now transverse to the
optical axis and loads the flexure joints in a direction they were not
pre-tensioned for.

> ⚠ The exact mapping of the two lateral flexure axes (which becomes vertical vs.
> horizontal) depends on **which face of the Z-motor** the microscope rests on.
> Confirm the physical resting face before CAD — it decides the gravity load
> direction on the flexure stage.

---

## 3. Mechanical concept — one shared base plate (Grundplatte)

**Key principle:** the **rail (with the moving microscope)** and the **fixed
reactor bridge (Brücke)** both mount to **one rigid base plate (Grundplatte)**.
Because both are referenced to the same foundation, the **optical-axis-to-sample
distance is fixed by construction** and cannot drift; the stationary row of
reactors stays coplanar and parallel to the rail. **Only the microscope
travels**; the reactors stand still and the imaging head drives along them.

The reactors **hang hochkant from above**: a continuous traverse board
("schmales Brett" in chip dimensions) spans the row on two end pillars, with a
cutout (Aussparung) per station from which each chip hangs. The tubes
(Schläuche) exit the chip tops through/above the board; the space **below** the
chips stays completely free so the moving mesoscope can reach every station
unobstructed (the stock illumination arm is removed from the model; a custom
light source behind the chips comes later as a separate part).

```
   (view along the rail, gravity ↓)      reactors FIXED & HANGING, microscope moves ⊙

   pillar ─┐  ┌───────────── traverse board (cutouts per station) ─────┐┌─ pillar
           ▓▓▓▓▓▓▓▓▓▓▓▓▓▓▓▓▓▓▓▓▓▓▓▓▓▓▓▓▓▓▓▓▓▓▓▓▓▓▓▓▓▓▓▓▓▓▓▓▓▓▓▓▓▓▓▓▓▓▓
           ║        ║ tubes ↑↑            ║                             ║
           ║      ┌─┴─┐  chip hochkant    ║   ┌───────────┐             ║
           ║      │ R │◄── optical axis ──╫───│ Microscope│ (tilted)    ║
           ║      └───┘  (through 16 mm)  ║   │ objective─┘◄─ light arm ║
           ║   free space below ▼         ║   └────┬──────┘             ║
           ║                              ║   ═════╪═════ rail X        ║
   ▓▓▓▓▓▓▓▓▓▓▓▓▓▓▓▓▓  base plate (Grundplatte) = shared foundation ▓▓▓▓▓▓▓▓▓▓▓
```

Sub-assemblies:
1. **Rail + carriage adapter** — the linear rail is bound under the microscope;
   the adapter interfaces the tilted microscope body (Z-motor face + an
   additional support) to the MGN12 carriage. Must resist the transverse gravity
   moment (long lever arm of the Pi5 + AI HAT + camera + optics tower).
2. **Reactor bridge (Brücke)** — a stationary traverse board with per-station
   cutouts, on two end pillars rising from the Grundplatte, holding the chips
   hanging hochkant at the correct height/spacing so each optical window lands
   on the optical axis. It is **not** attached to the carriage or the rail beam.
   The pillars stand `bridge_x_clear` beyond the end stations so the microscope
   body clears them at the end stops.

---

## 4. Rail & drive — recommendation

Decision was left open ("Empfehlungen?"). Recommendation:

| Element | Choice | Rationale |
|---|---|---|
| Foundation | **Base plate (Grundplatte)** | Shared reference for the rail and the fixed reactor bridge → fixed working distance. |
| Structural beam | **2040 V-Slot aluminium extrusion** | Stiff, cheap; carries the rail under the microscope, mounted on the Grundplatte. |
| Guide | **MGN12 profile rail + carriage** | Low play / high stiffness for the cantilevered microscope mass; clean mounting hole pattern. |
| Drive | **NEMA17 + T8 leadscrew (anti-backlash nut)** | Self-locking → holds position at each stop without current; no backlash for step-and-image. |
| Alt. drive | GT2 belt + NEMA17 | Faster, but slight backlash; only if scan speed matters more than repeatability. |

**Motor spec (decided 2026-09-02):** NEMA17 with **integrated Tr8×2 leadscrew**
("linear stepper", 3D-printer-Z style — no coupler, no shaft misalignment;
free spindle end gets a simple bearing in the 2040 profile end):
- 1.8°, ~40 Ncm holding torque, **rated current ≤ 1.5 A** (TMC2209 sustains
  ~1.2–1.4 A RMS; run at ~80 % of rated).
- **Tr8×2 lead (2 mm/rev)**, not the common Tr8×8: strongly self-locking
  (holds without current, guaranteed) and 0.01 mm/microstep — fine enough
  that the rail doubles as the horizontal fine-framing axis (§2). Speed
  ~5–10 mm/s is ample for 80 mm station hops.
- **Spindle length = scan length + ~60 mm** (nut + motor flange + end
  reserve); e.g. 5 reactors × 80 mm pitch → ~320 mm travel → 400 mm spindle.
- 0.9° versions unnecessary — final positioning is optical anyway.

**Why absolute rail repeatability is not critical:** the chip positions are
fixed by construction (shared Grundplatte), horizontal fine positioning is
done by the **rail drive itself** (Tr8×2, 0.01 mm/microstep — see §2), focus
by flexure-Z autofocus, and the vertical alignment is set once manually
(§7.1a). The rail only has to be **stiff** and repeat well enough to land
within the Tr8×2 fine-stepping range — which it trivially does.

**Alternatives considered:**
- *Fully printed dovetail guide* — rejected: not stiff enough for this mass over
  the required length.
- *MGN15* — viable if the loaded mass turns out higher than expected; heavier/costlier.

---

## 5. Gravity / flexure — the main risk

The OpenFlexure flexure stage is pre-tensioned for gravity **along** the optical
axis. Tilting 90° loads it **transversely**, which can cause sag, drift, or
changed backlash of the X/Y/Z flexures.

Mitigation ideas to evaluate at design/test time:
- Add a **secondary support** on the mount so the microscope body is clamped on
  **two faces**, not cantilevered off the Z-motor face alone.
- Check whether flexure **pre-load (O-rings / actuator tension)** needs adjusting
  for the new orientation.
- Empirically measure focus drift over a full X-scan before trusting positions.
- Consider counter-balancing or shortening the lever arm of the electronics tower.

This is the item most likely to force a design revision, so it is called out
explicitly and should be validated on a test print early.

---

## 6. Bioreactor chip — real geometry (STL integrated)

Source STL: `hardware/bioreactors/chip_senkrecht_mit_bodenplatte.stl` (ASCII/binary
STL, single chip). The file **includes a base plate (Bodenplatte)**; per
instruction the plate is **removed for the calculations** — it is a
mounting/handling feature, not part of the reactor envelope.

Measured (base plate excluded):

| Feature | Value | Axis in mount (hochkant, hanging) |
|---|---|---|
| Chip body width | **70 mm** | X (along rail) |
| Chip body thickness | **16 mm** | Y (**along the optical axis** — imaged through) |
| Chip body height | **40 mm** | Z (vertical, hanging from the bridge) |
| Optical window | **18 × 8 mm**, centered on the objective-facing (−Y) face, on the optical axis | window on optical axis |
| Fluidic ports | 4 × ⌀ ~4.5 mm, exiting the **top** edge (tubes go up) | — |
| Base plate (removed) | 140 × 100 mm thin panel | ignored for calculations |

**Orientation rationale:** the chip is imaged in **trans-illumination through
its 16 mm thickness** — light source on +Y, objective on −Y. The tubes leave
the ports on the top edge, so the chip cannot be accessed or held from above
by anything bulky and cannot rest on a shelf below (the mesoscope needs that
space); hence it **hangs hochkant from the bridge cutout**.

These values are now hard-wired as defaults in the SCAD reactor block. The rack
stays **parametric** (`n_reactors`, `reactor_pitch`, `reactor_w/d/h`, window
size) so the row length and stop spacing update automatically.

**Still to confirm:** the **series pitch** (reactor-to-reactor center distance
along X). The STL contains one chip only, so pitch is currently assumed
`reactor_pitch = 80 mm` (70 mm chip + 10 mm gap). Set this to the real rack
spacing once the multi-reactor frame is defined.

### 6.1 Standalone parametric rack (earlier drop-in concept)

A standalone parametric rack already exists at
`hardware/rails/openscad/bioreactor_rack.scad` (render:
`hardware/rails/openscad/build_rack.sh [N]` → `hardware/stl/models/bioreactor_rack_n<N>.stl`;
**no upstream OpenFlexure clone needed**). It was designed for the **earlier
retention concept** — the chip held **with** its base plate via a vertical
**drop-in slot + removable clamp**, plate **back face as the focus datum**,
`PITCH ≈ 148 mm`, and an `OPTICAL_AXIS_H` placeholder (60 mm).

The hochkant/bridge decision above (base plate **removed**, chips **hanging**,
pitch ≈ 80 mm, imaged through the 16 mm thickness) **supersedes** that base-plate
retention approach. This rack therefore still needs updating to the
hanging-bridge geometry — but the parametric `build_rack.sh` stays the tooling
entry point (and is documented as standalone in `CLAUDE.md`).

### 6.2 Illumination — custom trans-illumination source ("Halterung unten")

The stock OpenFlexure illumination arm (dovetail + condenser) is **removed from
the model** (§3, title block): the 16 mm chip leaves only ~1.5 mm under the stock
condenser, and light must come **from behind the chip row (+Y side)** for
trans-illumination through the 16 mm thickness → objective on −Y. A **custom
light source** on the +Y side is therefore an accepted follow-up part, not yet
designed.

**Reference candidate: ModLight** (Gibson et al. 2023, *HardwareX* 13, e00385;
DOI [10.5281/zenodo.7385903](https://doi.org/10.5281/zenodo.7385903); article
CC BY-4.0, design files CC BY-SA-4.0; PDF in `resources/Gibson_etal_2023 ModLight.pdf`).
Modular 3D-printed LED light sources (R/G/B/W + NIR) that deliver a **collimated
beam through a fibre/light guide**; demonstrated **directly on OpenFlexure**
(Delta stage) with modified `Condenser_Holder` and `Fibre_Holder` parts, and
provided as **OpenSCAD + STL + STEP** (fits our `hardware/*/openscad/` override
workflow).

Why it fits the rail mount specifically:
- **Fibre-coupled output decouples the LED/driver from the optics** — on the
  tilted/horizontal setup the light can be led to the +Y side behind the chips
  without mounting the (hot, heavy) source on the moving carriage or kipping it
  with the microscope. The collimated fibre tip is the only part that needs to
  sit behind each chip window.
- Multi-wavelength (R/G/B/W, NIR via the mirror variant) → multi-channel
  contrast for the NPU cell-classification pipeline.

### ✅ Decision (2026-10-07) — mirror variant, fibre on the moving head

The earlier open question ("multi-channel/NIR vs. monochrome; fixed per station
vs. fibre on the head") is **resolved**, driven by the target application:
**calcification imaging**.

- **Variant: mirror-based (MLight Box), NOT the X-Cube prism.** We image one
  channel at a time (step-and-image per station), so the X-Cube's *simultaneous*
  wavelength mixing is unnecessary, and only the **mirror variant reaches NIR**.
- **Topology: a single fibre-coupled source on the moving head** (+Y side) —
  not N fixed per-station sources. One LED set, heat/weight off the carriage and
  off the Pi-5/Hailo thermal budget; the collimator tip rides behind the chip in
  view.
- **Channels: Green (~525–530 nm) + White + NIR** (Red/Blue optional). Rationale:
  - **Green** maximises brightfield contrast of **Alizarin-Red-S**-stained
    calcium (the red Ca complex absorbs ~528–560 nm → complementary green).
  - **White** for overview and von-Kossa (dark) deposits.
  - **NIR** penetrates the thick, turbid 16 mm chip with less scattering and
    gives a label-free scattering signal from the birefringent hydroxyapatite
    nodules.
- **Caveat:** the mirror is magnet-held / **manually switched** in the published
  design → one channel per full scan pass in the prototype; motorising the
  mirror is a documented later option.

Design files are mirrored under `sources/modlight/` (gitignored): mirror source
`ModLight_Mirror/.../OpenSCAD/MSource File_OpenSCAD.scad`, common fibre parts
(collimator/holder/mount, PMMA mount, heatsink), the LED driver Gerber +
schematic under `Electronics/`, and the OpenFlexure-adapted
`Condenser_Holder_Modified` / `Fibre_Holder_Modified` (**STL only** — no SCAD
source, so any parametric override must be re-authored). See the build-script
caveats in `CLAUDE.md` for how overrides layer onto the upstream clone.

Thesis: captured in §4.3 (optical), §6 illumination driver, and the appendix BOM
(`thesis/`), with citation `Gibson2023`.

---

## 7. Open decisions / questions for next session

1. ✅ **Motor control architecture — REVISED (2026-09-02): Sangaboard removed,
   all-Python GPIO stage.** Supersedes the earlier (2026-08-26) "TMC2209
   Phase A/B with Sangaboard 4th axis" decision. Rationale: the DIY
   Sangaboard's ULN2003 cannot drive a NEMA17 (unipolar Darlington,
   ~500 mA/channel; NEMA17 is bipolar, ~1.2–1.5 A, needs a chopper driver);
   the flexure X/Y axes are functionless in the tilted setup anyway (§2);
   and dropping the Sangaboard HAT removes the 3-story HAT stack
   (thermal/5 V-budget concerns) plus the Arduino firmware maintenance
   entirely. **All remaining axes are driven directly from Pi 5 GPIOs by a
   pure-Python OpenFlexure stage class** (no serial protocol, no firmware).

   | Axis (world) | Function | Motor | Driver | GPIOs | Supply |
   |---|---|---|---|---|---|
   | Y (optical) | Focus (flexure Z → optics module) | 28BYJ-48 | ULN2003 | 4 | Pi 5 V |
   | X (rail) | Scan + horizontal fine framing | NEMA17 Tr8×2 | TMC2209 (standalone STEP/DIR/EN) | 3 (+2 UART opt.) | **12–24 V external** (only external consumer) |
   | Z (vertical) | deferred — see §7.1a | — | — | — | — |

   GPIO budget: ~7–9 of 28 (plus 3 more if the lift stage comes). Electrical
   notes: TMC2209 **VIO = 3.3 V** (never 5 V), common ground between Pi and
   VMOT supply mandatory, 100 µF electrolytic across VMOT, standalone current
   via poti (Vref ≈ 0.7 × I_RMS on common stepsticks), motor current ~80 %
   of rated. **De-energize the 28BYJ-48 after every move** (all 4 ULN inputs
   low; the flexure holds via O-ring pre-tension) so the 5 V budget stays
   clean for the Hailo-8. **Pi 5 gotcha:** `RPi.GPIO` does not work (RP1 I/O
   chip) — use `lgpio` / `gpiozero`. Python-side step timing is fully
   sufficient for step-and-image; drive the NEMA17 with a soft ramp, and
   generate the 28BYJ-48 half-step sequence in software (~30 lines).

   **TMC2209 wiring — two separate power domains (never mix them):**
   the high current (12–24 V, ~1.2–1.4 A) enters at the driver's **VM/VMOT
   screw terminal only** and flows out through **A1/A2/B1/B2** into the
   NEMA17 — it **never touches the Pi**. The Pi supplies only 3.3 V logic +
   three signal wires + a shared ground. The breakout is **not** plugged onto
   the Pi; it sits beside it, jumpered to the 40-pin header.

   ```
        ┌──────────── LOGIC SIDE (weak, 3.3 V) ────────────┐
   Pi 5 ── 3.3 V ─────────────► VIO   (never 5 V)          │
   40pin ── GND  ──────┬──────► GND (logic)                │
        ── GPIO ───────│──────► STEP  (1 pulse = 1 µstep)  │
        ── GPIO ───────│──────► DIR   (high/low)           │
        ── GPIO ───────│──────► EN    (enable)             │
        (opt) GPIO ────│──────► UART  (1 wire + resistor)  │
                       │        TMC2209 breakout           │
        ┌──────────────┴──── MOTOR SIDE (STRONG, 12–24 V) ─┤
   12–24 V PSU ─ + ──► VM/VMOT ┐  (screw terminal)         │
              ─ − ──► GND(mot) ┘                           │
                       └─ common ground with Pi GND ◄──────┘
        VM ══ 100 µF electrolytic ══ GND  (close to board)
        A1 A2 B1 B2 (screw terminal) ──► NEMA17 coils
   ```

   Mandatory: **both grounds joined** (Pi GND + PSU minus at the breakout GND)
   or STEP/DIR floats; **100 µF across VM/GND before first power-on**;
   set **Vref (≈ 0.7 × I_RMS)** at the poti *before* connecting the motor.

   Integration path: implement as a custom OpenFlexure-v3 stage class
   (the stage is already selected via `ofm_config.json.j2`, Dummy vs.
   Sangaboard today), deployed as a small package/patch by the `openflexure`
   Ansible role (analogous to the pisp patch). The `motor-controller` role
   is repurposed: arduino-cli/firmware/udev out, GPIO stage package +
   config in.

   > **Decision 2026-09-03: the Sangaboard stays for now** ("Sangaboard bleibt
   > vorerst implementiert") as a
   > **hybrid** — Sangaboard drives **focus (28BYJ-48) + illumination LED**
   > (both natively supported: the firmware has a PWM LED output and
   > OpenFlexure already controls Sangaboard illumination + axes out of the
   > box), while the **rail NEMA17** runs on a **standalone TMC2209 at GPIO**
   > (the Sangaboard's ULN can't drive it, so the TMC2209 is needed either
   > way). Trade-off: this removes the bare-GPIO focus + LED-PWM work
   > entirely, at the cost of keeping the HAT stack (5 V/thermal budget next
   > to the Hailo) and the Arduino firmware. Motivation: wiring the focus
   > motor and a dimmable illumination LED directly to GPIO turned out fiddly,
   > and the Sangaboard already solves exactly those two. Consequence: §7.1's
   > "all-Python GPIO stage" narrows to just the TMC2209 rail axis; the
   > Sangaboard's X/Y outputs stay unused. The X/Y motors + stage have been
   > removed from the body model (§8, `hardware/body/openscad/`).

   1a. **Vertical axis (world Z) — deferred, keep on the radar.** Baseline:
   **one-time manual height adjustment** at the carriage adapter (slotted
   holes / fine-pitch adjustment screw, then clamped) — all chips hang at
   the same height by construction. Motorization becomes necessary only if
   the field of view turns out **smaller than the window height (8 mm)** and
   vertical tiling is required → measure FOV at the chip window after the
   X-axis works. Expansion option, documented for then: a **mini lift stage
   (Hubtisch)** between MGN12 carriage and mesoscope adapter — two short
   vertical guides (MGN7/9 or bushings on 8 mm rods), NEMA17 + vertical
   Tr8×2 (3D-printer-Z principle), ~20 mm travel, self-locking → holds the
   ~2 kg without current. Cost: ~40–50 mm build height, ~200 g on the
   carriage, a second TMC2209 on the same VMOT supply, 3 more GPIOs.
   **Provision now:** give the carriage adapter a bolt pattern so the lift
   stage can be inserted later without reprinting the adapter.
2. **Resting face** on the Z-motor (confirms gravity load direction — §2).
3. **Scan length** = n × reactor pitch → beam length + leadscrew length.
4. **Bioreactor STL** → fixes rack geometry (§6).
5. ✅ **X as OpenFlexure axis — resolved by §7.1 (2026-09-02):** X becomes a
   normal axis of the custom all-Python GPIO stage class, so OpenFlexure
   scan/tiling/API features see it natively. No independent motion controller.

---

## 8. Next steps

- [x] Bioreactor STL integrated (`hardware/bioreactors/`), base plate removed,
      real chip dims wired into the SCAD draft.
- [x] Parametric standalone rack — `hardware/rails/openscad/bioreactor_rack.scad`
      (build: `hardware/rails/openscad/build_rack.sh [N]`). Embodies the earlier
      drop-in-slot/clamp concept (§6.1); **to be updated** to the hochkant/bridge geometry.
- [ ] Confirm the **series pitch** (reactor-to-reactor spacing) for the rack.
- [ ] Confirm the Z-motor resting face and measure the microscope's mass/CoG in
      the tilted orientation → also fixes `OPTICAL_AXIS_H` in the rack.
- [x] Decide stepper control path (§7.1, revised 2026-09-03): **hybrid** —
      Sangaboard keeps focus (28BYJ-48/ULN2003) + illumination LED, standalone
      TMC2209 at GPIO drives the rail; vertical axis deferred (§7.1a).
- [ ] Update the standalone rack (`hardware/rails/openscad/bioreactor_rack.scad`,
      §6.1) from the drop-in-slot/clamp concept to the hochkant/bridge geometry.
- [ ] Carriage adapter to MGN12 (the other sub-assembly, §3.1) — still blocked on
      the Z-motor resting face; new entry point under `hardware/rails/openscad/`,
      **with a bolt pattern for the optional lift stage** (§7.1a).
- [x] **Simplify the OpenFlexure model:** the X/Y flexure legs, actuator
      columns, motor lugs/cable housings and the **sample stage platform
      (Tisch)** are removed from the body — `hardware/body/openscad/`
      (`build_body.sh` → `main_body_mesoscope.stl`; upstream originals backed
      up alongside). Only the Z focus actuator + casing, inner wall/base with
      optics cut-out, outer walls and the four base lugs remain. Done
      2026-09-03; test print pending. Config (`ofm_config.json.j2`) still
      declares 3 axes — X/Y just have no motor attached.

### Handoff — fresh session starts here (2026-09-02)

1. **Verify upstream flexure axis mapping** (which axes move the stage
   platform vs. the optics module in the OpenFlexure CAD) — confirms the
   §2 insight before any mechanical design.
2. **Implement the rail axis** (`lgpio`: TMC2209 STEP/DIR with soft ramp for
   X) and bind it alongside the Sangaboard focus + illumination as an
   OpenFlexure-v3 stage class (selected via `ofm_config.json.j2`). Focus + LED
   stay on the Sangaboard; only the rail is new GPIO code.
3. **Rework the `motor-controller` Ansible role:** keep the Sangaboard path
   (arduino-cli / firmware / udev) for focus + LED; add the standalone TMC2209
   rail driver (GPIO stage package + wiring config).
4. **Measure the field of view at the chip window** → decide lift stage
   yes/no (§7.1a: needed only if FOV < 8 mm window height).
5. **Parts check/order for the X axis:** NEMA17 Tr8×2 linear stepper
   (≤1.5 A, spindle = scan + 60 mm), 2040 V-Slot, MGN12 rail + carriage,
   12–24 V supply. TMC2209 stepsticks already on hand.

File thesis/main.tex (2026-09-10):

%% ============================================================================
%%  Mesoscope — Master's Thesis
%%  A Low-Cost, Edge-AI Automated Microscope for Serial Monitoring of Cell
%%  Cultures in Perfused Bioreactor Chips
%%
%%  IEEEtran journal class. Build:  make   (pdflatex + bibtex + pdflatex x2)
%%  Content mirrors docs/THESIS_OUTLINE.md; figures live in ../hardware/assembly.
%% ============================================================================
\documentclass[journal,a4paper,10pt]{IEEEtran}

% --- packages -----------------------------------------------------------------
\usepackage[utf8]{inputenc}
\usepackage[T1]{fontenc}
\usepackage{graphicx}
\usepackage{amsmath,amssymb}
\usepackage{siunitx}
\usepackage{booktabs}
\usepackage{array}
\usepackage{multirow}
\usepackage{url}
\usepackage[hidelinks]{hyperref}
\usepackage{xcolor}

% figures are rendered in hardware/assembly (not committed — run build_exploded.sh)
\graphicspath{{figures/}{../hardware/assembly/}}

% siunitx setup
\sisetup{per-mode=symbol, range-phrase={--}, range-units=single}

% placeholder helper for content still to be produced (experiments not yet run)
\newcommand{\todo}[1]{\textcolor{red}{\textbf{[TODO: #1]}}}

% Include a figure if present (searched in the \graphicspath dirs), otherwise
% draw a framed placeholder. Keeps the build from hard-failing when the
% exploded-view PNGs have not been regenerated (they are not committed to git;
% run hardware/assembly/build_exploded.sh). #1 = file name, #2 = width.
\newcommand{\figorplaceholder}[2]{%
  \IfFileExists{../hardware/assembly/#1}{}{%
  \IfFileExists{figures/#1}{}{%
  \fbox{\parbox[c][0.5\columnwidth][c]{\dimexpr#2-2\fboxsep-2\fboxrule}{%
    \centering\todo{missing figure \texttt{\detokenize{#1}} --- regenerate with
    \texttt{hardware/assembly/build\_exploded.sh}}}}}}}

% ------------------------------------------------------------------------------
\begin{document}

\title{IDANA: A Low-Cost, Edge-AI Automated Mesoscope for Serial\\
Monitoring of Cell Cultures in Perfused Bioreactor Chips}

\author{Florian~Feigl%
\thanks{Master's thesis draft, compiled \today. Supervising faculty and formal
requirements to be confirmed (see \texttt{docs/THESIS\_ROADMAP.md}, milestone~M0).}%
\thanks{Project repository, cost data and CAD sources:
\texttt{docs/BOM\_COSTS.md}, \texttt{hardware/assembly/}.}}

\markboth{Master's Thesis --- IDANA Mesoscope}%
{Feigl: A Low-Cost, Edge-AI Automated Mesoscope for Bioreactor Chip Imaging}

\maketitle

\begin{abstract}
Continuous, non-destructive observation of adherent cell cultures inside
perfused bioreactor chips currently requires either manual microscopy---which
removes the chip from the incubator and is operator-dependent---or expensive,
closed, single-vessel commercial live-cell imagers. This thesis designs, builds
and validates \emph{IDANA}, a mesoscope: an OpenFlexure-derived microscope on a
Raspberry~Pi~5 with a Hailo-8 neural-processing unit, tilted onto its side and
mounted on a linear rail so that a single imaging head scans a rack of
bioreactor chips in series and analyses cell-level images on-device, without
external compute infrastructure. The contribution spans three axes: a
reproducible port of the OpenFlexure Server~v3 stack to the Pi~5 with a
custom C-mount high-quality-camera optics module; a tilted, rail-mounted
imaging form factor with a Z-focus-only body and a parametric bioreactor rack;
and an edge-AI cell-detection pipeline trained on CVAT annotations and deployed
on the Hailo-8. We evaluate the system against optical, mechanical, automation,
machine-learning and cost criteria. \todo{final quantitative results once
experiments in milestones M1--M6 are complete.}
\end{abstract}

\begin{IEEEkeywords}
Open-source microscopy, OpenFlexure, edge AI, Hailo-8, Raspberry~Pi, live-cell
imaging, bioreactor, cell detection, low-cost instrumentation.
\end{IEEEkeywords}

\IEEEpeerreviewmaketitle

% table of contents (not part of the IEEE paper style, kept for the thesis)
{\small\tableofcontents}

\input{sections/01_introduction}
\input{sections/02_background}
\input{sections/03_requirements}
\input{sections/04_optical_design}
\input{sections/05_mechanical_design}
\input{sections/06_electronics}
\input{sections/07_software}
\input{sections/08_edge_ai}
\input{sections/09_evaluation}
\input{sections/10_discussion}
\input{sections/11_conclusion}

\appendices
\input{sections/A_appendix}

% --- bibliography -------------------------------------------------------------
\bibliographystyle{IEEEtran}
\bibliography{references}

\end{document}

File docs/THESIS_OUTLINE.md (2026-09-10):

# Master's Thesis — Draft Outline

**Working title:** Mesoscope — A Low-Cost, Edge-AI Automated Microscope for Serial Monitoring of Cell Cultures in Perfused Bioreactor Chips

**Alternative (shorter):** Automated Edge-AI Cell Imaging of Bioreactor Arrays with an Open-Source Mesoscope

> Naming: the former project acronym "CELLAIR" is retired. `README.md`, `CLAUDE.md`, `ansible/README.md` and `ansible/inventory/README.md` still carry it and need renaming (see roadmap M0). Cost data: `BOM_COSTS.md`. Exploded view: `hardware/assembly/`.

Language: English · Scope: system (hardware + infrastructure) **and** ML pipeline · Duration: 9–12 months
See `THESIS_ROADMAP.md` for the schedule and `THESIS_PARAMETER_GAPS.md` for the documentation audit.

---

## 1. Problem statement & research questions

Continuous, non-destructive observation of adherent cell cultures inside perfused bioreactor chips
(e.g. hFOB 1.19 osteoblasts, hMEC 1 endothelial cells under pressure/flow test series) currently
requires either manual microscopy (removes the chip from the incubator, operator-dependent,
low temporal resolution) or commercial live-cell imagers (expensive, closed, single-vessel).

This thesis builds and validates a **mesoscope**: an OpenFlexure-derived microscope on a
Raspberry Pi 5 with a Hailo-8 NPU, mounted horizontally on a linear rail so that one imaging head
scans a rack of bioreactor chips in series, and evaluates cell-level images on-device without
external compute infrastructure.

**RQ1 (System):** Can an open-source, sub-500 EUR microscope built from OpenFlexure, a Pi HQ camera
and 3D-printed parts deliver image quality (resolution, FOV, focus stability) sufficient for
automated cell analysis in a bioreactor chip through its observation window?

**RQ2 (Automation):** Can a single imaging head on a linear X-rail revisit N bioreactors
autonomously with positioning repeatability and autofocus reliability adequate for time-lapse
monitoring over days inside an incubator?

**RQ3 (Edge AI):** Can a cell-detection/segmentation model trained on data annotated in CVAT be
deployed on the Hailo-8 NPU with accuracy (mAP / IoU / count error) and throughput sufficient
for on-device, near-real-time analysis — and how does it compare to inference on the Pi CPU
and to manual counting?

**Hypotheses / success criteria (to be finalised):**
- H1: Measured lateral resolution ≤ 1.5 µm (USAF 1951; Rayleigh limit 1.1 µm at NA 0.30) and FOV ≥ 0.5 mm² with the ZEISS Plan-Neofluar 10×/0.30 + 125 mm tube lens.
- H2: Rail positioning repeatability ≤ ±10 µm; autofocus success rate ≥ 95 % across ≥ 3 chips over 72 h.
- H3: Cell detection mAP@0.5 ≥ 0.8 on held-out chips; Hailo-8 inference ≥ 10× faster than Pi CPU at equal accuracy (±2 % mAP).

## 2. Proposed structure

| # | Chapter | Content | Source material in repo |
|---|---|---|---|
| 1 | Introduction | Motivation, problem statement, RQ1–3, contributions, thesis structure | — (to write) |
| 2 | Background & Related Work | Live-cell imaging, open-hardware microscopy (OpenFlexure, UC2, Squid), edge AI on NPUs, cell detection/segmentation (YOLO, Cellpose, StarDist), microfluidic/perfused bioreactor chips | — (literature) |
| 3 | Requirements & System Concept | Use case (N chips in series in incubator), functional/non-functional requirements, architecture overview, design decisions (Pi 5 + Hailo, OFM v3, horizontal tilt, rail) | `README.md` architecture diagram, `docs/RAIL_MOUNT_CONCEPT.md` §1–3 |
| 4 | Optical Design | Sensor/objective/tube-lens calculation, magnification, sampling, resolution budget, C-mount module design, illumination | `hardware/optics/OPTICS_MODULE.md`, `hardware/optics/openscad/README.md`, `hardware/optics/CORRESPONDENCE.md` |
| 5 | Mechanical Design | Z-focus-only body, stand & electronics drawer, 90° tilt mount, V-slot rail + carriage, bioreactor rack, print parameters, tolerances | `hardware/body/…/README.md`, `hardware/stand/…/microscope_stand_readme.md`, `docs/RAIL_MOUNT_CONCEPT.md` §4–6, `hardware/PRINT_CHECKLIST.md` |
| 6 | Electronics & Motion Control | Pi 5 / AI HAT+ / RTC stack, focus stepper (28BYJ-48 + ULN2003), rail stepper (NEMA17 + TMC2209), power budget, GPIO stage driver | `docs/RAIL_MOUNT_CONCEPT.md` §7, `hardware/firmware/README.md` |
| 7 | Software & Infrastructure | Ansible provisioning, OpenFlexure v3 port to Pi 5 (pisp, pipewire, DKMS fixes), camera configuration, calibration (CSM), scan/time-lapse orchestration, CVAT server | `ansible/`, `docs/OPENFLEXURE_SUITE.md`, `docs/CSM_CALIBRATION_RPI5.md`, `docs/BIOREACTOR_POSITION.md`, `ansible/README.md` |
| 8 | Edge-AI Pipeline | Data acquisition protocol, CVAT label schema, dataset statistics, model selection, training, HEF compilation (Hailo Dataflow Compiler), deployment on the Pi | — (to build; `model/` planned) |
| 9 | Evaluation | Optical (resolution, FOV, flat-field), mechanical (repeatability, drift, tilt stiffness), automation (multi-chip time-lapse), ML (accuracy, latency, CPU vs NPU), cost & build time, comparison to reference microscope | partly: `docs/CSM_CALIBRATION_RPI5.md`, README benchmark |
| 10 | Discussion | Answers to RQ1–3, limitations, lessons learned (Pi 5 breakage, tilt risks), generalisation | — |
| 11 | Conclusion & Outlook | Contributions, future work (fluorescence, multi-rail, closed-loop control) | — |
| A | Appendices | BOM, print settings, wiring diagrams, Ansible variable reference, dataset card, model card, calibration logs | `README.md` BOM, `hardware/PRINT_CHECKLIST.md` |

## 3. Contributions (as they should appear in ch. 1)

1. Port of OpenFlexure Server v3 to Raspberry Pi 5 / Trixie with reproducible Ansible provisioning, including documented fixes for the Pi 5 ISP, camera stack and Hailo driver.
2. A C-mount HQ-camera optics module with 125/150 mm tube lens for the IMX477, with full optical derivation and printable CAD.
3. A tilted, rail-mounted imaging head with a Z-focus-only body and parametric bioreactor rack — a new form factor for serial monitoring of multiple chips.
4. An all-Python GPIO stage driver replacing the Sangaboard (to be confirmed — see open decision below).
5. A CVAT-annotated cell dataset from bioreactor-chip images and a Hailo-8-deployed detection model with a CPU-vs-NPU evaluation.
6. Quantitative validation of the complete system against stated requirements.

## 4. Open decisions that must be fixed before writing

| Decision | Current state | Needed by |
|---|---|---|
| Motor architecture: Sangaboard hybrid vs. all-Python GPIO | Contradictory across `CLAUDE.md`, memory and `RAIL_MOUNT_CONCEPT.md` (2026-09-03 note) | Roadmap M2 |
| Objective: **ZEISS Plan-Neofluar 10×/0.30** — confirm tube-length marking (`160/-` finite vs. `∞/0.17` ICS) and thread (RMS vs. M27); the optics module assumes 160 mm finite + RMS | Model known; marking/thread unverified; docs still say "scraped ≤10×" | M1 |
| Biological readout: what is measured (confluence, cell count, morphology, migration, calcification)? | Not defined | M1 (drives label schema + evaluation) |
| Bioreactor pitch / rack geometry | 80 mm assumed, unconfirmed; `bioreactor_rack.scad` still on old concept | M3 |
| ML task: detection vs. segmentation; model family (YOLOv8-seg, Cellpose-lite, StarDist) | Only a foreign YOLOv8s-Pose benchmark exists | M4 |
| Reference method for ground truth (manual count, commercial microscope, trypan blue?) | Not defined | M4 |
| Supervising faculty / formal requirements (page count, template, colloquium) | Open | now |

## 5. Documentation gaps (summary — full list in `THESIS_PARAMETER_GAPS.md`)

- **Not written anywhere:** research question, biological experiment design, imaging schedule, measured FOV/resolution, dataset, labels, model metrics, power budget, wiring diagram, exact software versions/commits.
- **Inconsistent between files:** IMX477 sensor size (7.857×5.893 vs. 6.287×4.712 mm), camera exposure values (20 ms/1.5/[1.4,2.3] vs. 492 µs/1.0/[0.9,2.9]), tube-lens magnification (0.49 vs. 0.515), motor architecture.
- **Only calculated, not measured:** resolution, FOV, sensor fill, working distance.

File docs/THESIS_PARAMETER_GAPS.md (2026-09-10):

# Thesis Parameter Audit — documented vs. missing

Audit of the repository documentation (state: 2026-09-08) against what a master's thesis must report.
"Documented" = value + source file exists. "Missing" = not written down, only implicit, or contradictory.

## 1. Optics

| Parameter | Status | Value / note | Source |
|---|---|---|---|
| Sensor active area | documented, **inconsistent** | 6.287 × 4.712 mm (corrected) vs. 7.857 × 5.893 mm (README, OPENFLEXURE_SUITE.md) | `hardware/optics/OPTICS_MODULE.md` |
| Pixel pitch | documented | 1.55 µm | OPTICS_MODULE.md |
| Tube lens | documented | 125 / 150 mm achromat, Ø12.7 mm, BFD 124.1 / 148.8 mm | `hardware/optics/openscad/README.md` |
| Tube magnification | documented, **inconsistent** | 0.469 / 0.515; calculation elsewhere uses 0.49 | OPTICS_MODULE.md |
| C-mount flange distance | documented | 17.526 mm | OPTICS_MODULE.md |
| Objective | known, **not yet in repo docs** | ZEISS Plan-Neofluar 10×/0.30 (stated 2026-09-08). Confirm marking `160/-` vs `∞/0.17` and thread RMS vs M27; parfocal 45 mm. README/OPTICS_MODULE.md still say "scraped ≤10×, NA 0.25" | — |
| Resolution | calculated only, **stale NA** | docs: Rayleigh 1.3 µm at NA 0.25 → with NA 0.30: 1.12 µm (λ 550 nm); sampling 0.32 µm/px unchanged | OPTICS_MODULE.md |
| Field of view | **missing** (TODO) | "measure FOV at chip window" | RAIL_MOUNT_CONCEPT.md |
| Working distance | measured from STL | 3.35 mm | RAIL_MOUNT_CONCEPT.md |
| Illumination | partial | PMMA condenser 13 mm / f 5 mm; LED type, wavelength, power **missing** | — |
| Flat-field / lens shading | **missing** | roadmap item only | README |

## 2. Camera

| Parameter | Status | Value / note | Source |
|---|---|---|---|
| Modes | documented | 4056×3040 @10 fps, 2028×1520 @30 fps | README |
| Exposure / gain / colour gains | documented, **stale copies** | 492 µs / 1.0 / [0.9, 2.9] (tested); README + OPENFLEXURE_SUITE.md still list 20 ms / 1.5 / [1.4, 2.3] | `docs/BIOREACTOR_POSITION.md` |
| AE / AWB | documented | disabled | BIOREACTOR_POSITION.md |
| CSM matrix, fit error, backlash | documented | [[−19.80, 0.04], [−0.06, 19.26]], 1.6/1.7 %, 158/84 steps, ≈0.025 px/step | `docs/CSM_CALIBRATION_RPI5.md` |
| Image orientation | documented | vertical flip (commit f3d4bff) | git |
| Snapshot format (JPEG quality, bit depth, RAW) | **missing** | — | — |
| Noise / SNR characterisation | **missing** | — | — |

## 3. Mechanics

| Parameter | Status | Value / note | Source |
|---|---|---|---|
| Print settings | documented | PLA black, 0.15/0.2 mm layer, 3 walls, 20–30 % infill | `hardware/PRINT_CHECKLIST.md` |
| C-mount seat | documented | Ø32.6 mm, 0.3 mm clearance | optics README |
| Drawer stack heights | documented | 5.5 / 18.4 / 34.2 mm | `microscope_stand_readme.md` |
| Bioreactor chip | documented | 70 × 40 × 16 mm, window 18 × 8 mm, 4 ports Ø4.5 | RAIL_MOUNT_CONCEPT.md §6 |
| Rail | documented | 2040 V-slot, MGN12, NEMA17 Tr8×2 (2 mm/rev, 0.01 mm/µstep) | RAIL_MOUNT_CONCEPT.md |
| Working gap | documented | 10 mm | RAIL_MOUNT_CONCEPT.md |
| Reactor pitch | **assumed** | 80 mm, unconfirmed; `bioreactor_rack.scad` still PITCH=148 | rails/openscad |
| Focus resolution (µm/step, 28BYJ-48 + flexure) | **missing** | only px/step indirectly | — |
| Z travel | **missing** | — | — |
| Tilted mass / centre of gravity / stiffness / drift | **missing** | named as risk, not measured | RAIL_MOUNT_CONCEPT.md §5 |
| Print tolerances (measured) | **missing** | — | — |

## 4. Electronics

| Parameter | Status | Value / note | Source |
|---|---|---|---|
| Compute | documented | Pi 5 8 GB, AI HAT+ Hailo-8 26 TOPS, FW 4.23.0, DS3231, 27 W PSU | README BOM |
| TMC2209 wiring, Vref, decoupling | documented | VIO 3.3 V, 100 µF, Vref ≈ 0.7 × I_RMS, 12–24 V | RAIL_MOUNT_CONCEPT.md §7.1 |
| GPIO budget | documented | 7–9 pins | RAIL_MOUNT_CONCEPT.md |
| Resource profile | documented | CPU load 0.71, 762 MB RAM, 48 °C | README |
| Power budget (5 V rail with Hailo + ULN2003) | **missing** | only a concern | — |
| Schematic / pinout table | **missing** | — | — |
| Motor architecture | **contradictory** | "Sangaboard removed" (CLAUDE.md, memory) vs. hybrid note 2026-09-03 | RAIL_MOUNT_CONCEPT.md |

## 5. Software / infrastructure

| Parameter | Status | Value / note | Source |
|---|---|---|---|
| OS / Python | documented | Pi OS Trixie, Python 3.13 | README |
| OpenFlexure | documented | v3 branch, 3.0.0-alpha4 | README, ansible role |
| Pi 5 fixes | documented | pisp, pipewire, DKMS ordering, SupplementaryGroups | ansible roles, README |
| CVAT deployment | documented | Docker + Caddy, cvat.feigl.dev | `ansible/README.md` |
| NPU benchmark | documented (foreign model) | YOLOv8s-Pose 91.5 inf/s, 10.9 ms | README |
| Exact versions / commit hashes (OFM, picamera2, libcamera, HailoRT, DFC) | **missing** | — | — |
| Time-lapse / scan orchestration script | **missing** | `capture_timelapse.py` referenced, does not exist | OPENFLEXURE_TESTING.md |
| ML: model, dataset, labels, metrics, `model/` dir | **missing entirely** | — | — |
| CVAT label schema / annotation guideline | **missing** | — | — |

## 6. Biology / application

| Parameter | Status | Value / note | Source |
|---|---|---|---|
| Cell lines | mentioned only | hFOB 1.19, hMEC 1 | README diagram |
| Experiment keywords | mentioned only | calcification, pressure/flow series, PFA-fixed, 37 °C incubator | README Phase 6 |
| Bioreactor type / manufacturer, medium, flow rates, seeding density, culture duration | **missing** | — | — |
| Imaging interval, number of chips, positions per chip | **missing** | — | — |
| Measured quantity (confluence, count, morphology, migration) | **missing** | — | — |
| Controls, replicates, experimental design | **missing** | — | — |
| Provenance / ethics of cell lines | **missing** | — | — |

## 7. Evaluation

| Parameter | Status | Value / note | Source |
|---|---|---|---|
| CSM ground-truth check | documented | +500/1000/2000 steps → 12.7/24.6/48.7 px | CSM_CALIBRATION_RPI5.md |
| Example images | documented | 4 images, 2026-08-04 … 08-17 | `resources/`, `docs/presentation.tex` |
| Resolution / FOV measurement (USAF, stage micrometer) | **missing** | — | — |
| Focus drift / repeatability (tilted) | **missing** | — | — |
| Rail positioning repeatability | **missing** | — | — |
| Image-quality metrics, flat-field residual | **missing** | — | — |
| Model metrics (mAP, IoU, count error), CPU vs. NPU | **missing** | — | — |
| Comparison with reference microscope | **missing** | — | — |
| Cost / build-time balance | partial | BOM prices only | README |

## 8. Framing

- **Research question / problem statement:** not stated anywhere. README has title and a diagram note ("without external compute infrastructure"); `presentation.tex` is an image gallery.
- **Done:** OFM v3 Pi 5 port, HQ camera + exposure, Hailo inference (foreign model), optics calculation + STLs, stand/drawer, CSM calibration, rail concept + massing CAD, Z-only body (SCAD).
- **Open:** print + assemble optics module, body/drawer test prints, rail hardware, GPIO stage class, rack update, FOV measurement, flat-field, incubator setup, entire ML pipeline, all biological experiments.

## Immediate housekeeping (before any thesis writing)

1. Fix sensor-size, camera-value and tube-magnification inconsistencies (README, OPENFLEXURE_SUITE.md, OPTICS_MODULE.md).
2. Record the motor-architecture decision in one place and align CLAUDE.md / RAIL_MOUNT_CONCEPT.md.
3. Add a `docs/VERSIONS.md` with pinned commits/versions (OFM, picamera2, libcamera, HailoRT, Hailo DFC, kernel).
4. Update OPTICS_MODULE.md and README BOM to the ZEISS Plan-Neofluar 10×/0.30 (NA 0.30, resolution 1.12 µm; verify tube length + thread).
5. Remove or implement the referenced `capture_timelapse.py`.
6. Retire the "CELLAIR" name in README.md, CLAUDE.md, ansible/README.md, ansible/inventory/README.md.

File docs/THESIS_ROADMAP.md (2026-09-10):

# Master's Thesis — Roadmap (9–12 months)

Start assumed 2026-10-01; submission window 2027-07 … 2027-09.
Milestones M0–M7; each has an exit criterion. Writing runs in parallel from M2 onward (chapter
numbers refer to `THESIS_OUTLINE.md`). Buffer of ~6 weeks is built into the 12-month variant.

```
        Oct  Nov  Dec  Jan  Feb  Mar  Apr  May  Jun  Jul  Aug  Sep
M0 Frame ██
M1 Optics    ████
M2 Motion         ████
M3 Rail                ████████
M4 Data/ML                  ████████████
M5 Biology                            ████████
M6 Evaluation                              ████████
M7 Writing   ░░░░░░░░░░░░░░░░░░░░░░░░░░████████████
Buffer                                                  ████
```

## M0 — Framing & housekeeping (Oct 2026, 3–4 weeks)

Goal: thesis registered, research questions fixed, documentation contradiction-free.

- [ ] Confirm faculty, supervisor(s), formal requirements (template, page count, colloquium date).
- [ ] Finalise RQ1–3 and success criteria H1–H3 with supervisor (`THESIS_OUTLINE.md` §1).
- [ ] Define the **biological readout** (confluence / cell count / morphology / calcification) — this decides the ML task and label schema.
- [ ] Resolve motor-architecture decision (Sangaboard hybrid vs. all-GPIO) and write it down once.
- [ ] Fix documented inconsistencies (sensor size, camera values, tube magnification) and retire the "CELLAIR" name — `THESIS_PARAMETER_GAPS.md` §"Immediate housekeeping".
- [ ] Create `docs/VERSIONS.md` (pinned commits/versions) and a literature database (Zotero) with ≥ 30 initial references.
- [ ] Set up thesis LaTeX repo (or `thesis/` dir) with CI build.

**Exit:** signed registration; RQs written; no contradictions in repo docs.

## M1 — Optics module & imaging validation (Nov–Dec 2026, 6 weeks)

Goal: RQ1 answerable. Ch. 4 draftable.

- [ ] Objective is a ZEISS Plan-Neofluar 10×/0.30: verify tube-length marking (160 mm finite vs. ∞) and thread (RMS vs. M27 → adapter or optics-module change), update `OPTICS_MODULE.md` (NA 0.30 → 1.12 µm Rayleigh).
- [ ] Print and assemble 125 mm optics module (`build_optics.sh 125`); assemble Z-only body (`build_body.sh mesoscope`), stand and drawer.
- [ ] Measure: lateral resolution (USAF 1951 target), FOV (stage micrometer), sensor fill, working distance at the chip window, focus repeatability (Z stepper).
- [ ] Flat-field / lens-shading calibration; document illumination (LED type, wavelength, power, condenser).
- [ ] Image a real bioreactor chip through its window (fixed cells) — first "hero" images for ch. 4/9.
- [ ] Decide 125 vs. 150 mm tube lens on measured data.

**Exit:** resolution/FOV/flat-field table exists; H1 evaluated (pass or documented deviation).

## M2 — Motion control & software stage (Dec 2026–Jan 2027, 6 weeks)

Goal: focus + rail drivable from OpenFlexure; ch. 6–7 draftable.

- [ ] Implement the GPIO stage class (ULN2003 focus + TMC2209 rail) or Sangaboard hybrid per M0 decision; wire into `ofm_config.json.j2`.
- [ ] Measure focus µm/step and Z travel; re-run CSM calibration (`csm_calibrate_rpi5.py`) on the assembled unit.
- [ ] Validate OpenFlexure autofocus on the chip window (success rate over ≥ 50 trials).
- [ ] Wiring diagram + pinout table + power budget (5 V rail with Hailo under load; 12–24 V motor supply).
- [ ] Implement `capture_timelapse.py` / scan orchestration (positions × interval × chips → timestamped images + metadata JSON).
- [ ] Update Ansible so a fresh Pi reproduces the full stack in one run (document run time).

**Exit:** autofocus success rate measured; time-lapse of one chip over 24 h captured unattended.

## M3 — Rail mount & bioreactor rack (Jan–Feb 2027, 8 weeks; overlaps M2/M4)

Goal: RQ2 answerable; ch. 5 draftable.

- [ ] Order rail hardware (2040 V-slot, MGN12, NEMA17 + Tr8×2, TMC2209, PSU).
- [ ] Confirm bioreactor pitch and rack geometry with the biology side; update `bioreactor_rack.scad` and `rail_mount_mesoscope.scad`.
- [ ] Print/assemble tilt mount, carriage, rack (N=3); measure tilted mass, centre of gravity, deflection.
- [ ] Measure rail positioning repeatability (dial gauge + image-based, ≥ 20 cycles), focus drift after tilt over 12 h, thermal drift in the incubator.
- [ ] Multi-chip scan: 3 chips × k positions, 72 h in incubator, unattended.
- [ ] Incubator integration: cable routing, humidity/condensation protection, heat of Pi + Hailo inside the incubator (temperature log).

**Exit:** H2 evaluated; 72 h multi-chip time-lapse dataset exists.

## M4 — Dataset & Edge-AI pipeline (Feb–Apr 2027, 12 weeks)

Goal: RQ3 answerable; ch. 8 draftable.

- [ ] Data-acquisition protocol (which chips, cell densities, magnifications, illumination) and dataset card.
- [ ] CVAT label schema + annotation guideline; annotate ≥ 300 images (or ≥ 5 000 instances); inter-annotator check on a subset (≥ 30 images, 2 annotators).
- [ ] Train/val/test split **by chip** (no leakage); baseline models: YOLOv8-n/s (det or seg) vs. Cellpose/StarDist; report mAP@0.5, IoU, count MAE.
- [ ] Compile best model with Hailo Dataflow Compiler → `.hef`; measure accuracy delta after quantisation.
- [ ] Deploy on Pi 5: HailoRT inference service consuming the time-lapse output; measure latency/throughput NPU vs. CPU (ONNX Runtime) vs. reference GPU.
- [ ] Ground-truth method for cell counts (manual count on reference microscope or trypan blue) defined and applied to the test set.
- [ ] Create `model/` with training config, `requirements.txt`, and tests so the existing CI job becomes real.

**Exit:** H3 evaluated; model card + dataset card written; inference runs on-device end-to-end.

## M5 — Biological application study (Apr–May 2027, 8 weeks; overlaps M4/M6)

Goal: demonstrate the system on a real question, not just a benchmark. Ch. 9 application section.

- [ ] Experimental design with the biology side: cell lines (hFOB 1.19 / hMEC 1), medium, seeding density, flow/pressure conditions, replicates, controls, duration.
- [ ] Run ≥ 1 full monitoring campaign (e.g. 3 chips, 2 conditions, 5–7 days, imaging every 2 h).
- [ ] Derive the readout time series (confluence/count/morphology) automatically; compare to end-point reference measurement.
- [ ] Document failures (focus loss, condensation, motor stalls) quantitatively — this is thesis material.

**Exit:** one complete campaign with automated readout and reference comparison.

## M6 — Evaluation & consolidation (May–Jun 2027, 6 weeks)

- [ ] Consolidate all measurements into ch. 9 tables/figures (optics, mechanics, automation, ML, cost, build time).
- [ ] Cost/time balance vs. commercial live-cell imager; reproducibility check: second person rebuilds from repo + Ansible (log time and problems).
- [ ] Error analysis and limitations for ch. 10.

## M7 — Writing & submission (Jun–Sep 2027)

- Writing is continuous from M1 (target: chapter draft ≤ 2 weeks after each milestone). Ch. 2 literature review written during M1–M2 idle time (print jobs, orders).
- [ ] Full draft to supervisor by end of Jun 2027; revision loop July.
- [ ] Final figures, appendices (BOM, print settings, wiring, dataset/model cards, Ansible variable reference).
- [ ] Submission target Aug 2027 (12-month variant: Sep 2027). Colloquium prep.

## Risks & mitigations

| Risk | Likelihood | Impact | Mitigation |
|---|---|---|---|
| Tilted flexure drifts / loses focus | medium | high | Measure early in M3; fallback: horizontal-window chip holder with microscope upright, or stiffening brace |
| Rail hardware lead time | medium | medium | Order in M0/M1, not M3 |
| Too few cells / poor contrast through chip window for ML | medium | high | M1 hero images decide early; fallback: fixed/stained reference slides for the ML chapter, chip images as transfer test |
| Hailo DFC quantisation kills accuracy | low–medium | medium | Report CPU path as valid result; NPU as speed-up with documented accuracy delta |
| Biology campaign slips (cell availability, incubator time) | high | medium | Decouple: RQ1–3 must be answerable without M5; M5 is the "application" bonus |
| Scope creep (fluorescence, more rails, dashboards) | high | high | Anything not in RQ1–3 goes to Outlook |
| Pi 5 stack breakage after OS/OFM updates | medium | medium | Pin versions (`VERSIONS.md`), snapshot SD image after M2 |

## Minimum viable thesis (if time runs out)

RQ1 + RQ3 with a single stationary chip (no rail), model trained on fixed-cell images, NPU vs. CPU evaluation. RQ2/rail becomes a designed-and-partially-validated chapter plus outlook. Decide by end of M3 (Feb 2027).

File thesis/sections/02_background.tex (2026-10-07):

\section{Background and Related Work}
\label{sec:background}

\subsection{Live-cell and in-incubator imaging}
Live-cell imaging observes cultures over time under controlled temperature,
humidity and CO\textsubscript{2}. Commercial in-incubator systems (e.g.\ IncuCyte-class
instruments) automate multi-well time-lapse acquisition but are closed and
costly. This thesis targets the specific case of \emph{perfused bioreactor
chips}, where the sample is a sealed microfluidic device observed through a
small optical window rather than an open well plate. The concrete target
readout is \emph{calcification} monitoring---calcium deposits revealed by
Alizarin Red~S or von~Kossa staining---which motivates the multi-channel
(green / white / near-infrared) trans-illumination chosen in
Section~\ref{sec:optical}.
\todo{cite the specific commercial baseline and the bioreactor-chip platform
used in the wet-lab experiments.}

\subsection{Open-hardware microscopy}
The OpenFlexure Microscope \cite{Collins2020,Sharkey2016} is a 3D-printed,
flexure-based motorised microscope driven by a Raspberry~Pi and a Pi camera; it
provides sub-micron mechanical stepping via a monolithic flexure stage and an
established software stack (OpenFlexure Server). Related open platforms include
UC2 \cite{Diederich2020} (modular cube-based optics) and the Squid/Octopi
family \cite{Li2020Squid} (higher-performance automated imaging). The mesoscope
reuses the OpenFlexure optics and Z-focus mechanics but departs from the XY
flexure stage: it removes lateral flexure motion and instead tilts the whole
body and translates it along an external linear rail
(Section~\ref{sec:mechanical}).

\subsection{Edge AI on neural-processing units}
On-device inference avoids transferring images off the instrument and enables
near-real-time analysis inside the incubator. The Raspberry~Pi AI~HAT+ carries a
Hailo-8 NPU (\SI{26}{TOPS}); models must be compiled to the Hailo Executable
Format (HEF) with the Hailo Dataflow Compiler and quantised to run on the NPU.
\todo{cite Hailo-8 architecture / dataflow compiler documentation.}

\subsection{Cell detection and segmentation}
Candidate model families for counting and delineating cells include
general-purpose detectors and instance segmenters (YOLOv8 and variants) and
cell-specific segmentation models such as Cellpose \cite{Stringer2021Cellpose}
and StarDist \cite{Schmidt2018StarDist}. The choice between bounding-box
detection and instance segmentation---and thus the CVAT label schema---depends
on the biological readout (confluence, count, morphology, migration), which is
an open decision fixed in milestone~M1
(Section~\ref{sec:requirements}). Only a foreign YOLOv8s-Pose benchmark
currently exists in the project; the task-specific model is built in
Section~\ref{sec:edgeai}.

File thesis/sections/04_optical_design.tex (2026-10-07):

\section{Optical Design}
\label{sec:optical}

\subsection{Imaging chain}
The imaging chain is: bioreactor chip $\rightarrow$ ZEISS Plan-Neofluar
$10\times/0.30$ objective $\rightarrow$ achromatic tube lens
($f = \SI{125}{\milli\meter}$, $\varnothing\,\SI{12.7}{\milli\meter}$)
$\rightarrow$ Raspberry~Pi HQ camera (Sony IMX477, C-mount). A
\SI{150}{\milli\meter} tube lens is held as a spare for a longer effective focal
length.

\subsection{Objective}
The objective is a ZEISS Plan-Neofluar $10\times/0.30$ (numerical aperture
NA~$=0.30$). Its diffraction-limited (Rayleigh) lateral resolution at
$\lambda = \SI{550}{\nano\meter}$ is
\begin{equation}
  d = \frac{0.61\,\lambda}{\mathrm{NA}}
    = \frac{0.61 \times \SI{550}{\nano\meter}}{0.30}
    \approx \SI{1.1}{\micro\meter}.
  \label{eq:rayleigh}
\end{equation}
\todo{confirm the objective's tube-length marking ($160/-$ finite versus
$\infty/0.17$ ICS) and thread (RMS versus M27); the current optics module
assumes a \SI{160}{\milli\meter} finite objective with an RMS thread
(open decision, milestone~M1).}

\subsection{Sensor, magnification and sampling}
The IMX477 sensor is $6.287 \times \SI{4.712}{\milli\meter}$ with
\SI{1.55}{\micro\meter} pixels. With a nominal system magnification of
$\approx 0.515$ from the $10\times$ objective de-rated by the finite tube lens,
the object-space field of view and pixel sampling follow from the sensor
dimensions divided by the magnification. The resulting sampling comfortably
Nyquist-samples the $\approx\SI{1.1}{\micro\meter}$ optical resolution.
\todo{tabulate the exact magnification, object-space FOV and object-space pixel
pitch once the objective marking and tube-length are confirmed; the repo docs
currently disagree on the sensor size
($7.857\times\SI{5.893}{\milli\meter}$ versus
$6.287\times\SI{4.712}{\milli\meter}$) and on magnification ($0.49$ vs.\ $0.515$)
--- resolve before finalising (see \texttt{docs/THESIS\_PARAMETER\_GAPS.md}).}

\subsection{C-mount optics module}
The tube lens is held in a printed C-mount module
(\texttt{optics\_hq\_125\_rms\_threaded.stl}) that mates the objective thread to
the HQ camera C-mount and sets the tube-lens-to-sensor spacing. The module and
its build script are documented in \texttt{hardware/optics/}.

\subsection{Illumination}
The stock OpenFlexure condenser arm cannot clear the \SI{16}{\milli\meter}-thick
bioreactor chip, so it is removed from the model and trans-illumination is
provided from behind the chip row (the $+Y$ side), passing through the
\SI{16}{\milli\meter} chip thickness to the objective on $-Y$
(\texttt{docs/RAIL\_MOUNT\_CONCEPT.md}, \S6.2). Rather than a fixed source per
station, a single collimated source is fibre-coupled and carried on the moving
imaging head, which keeps the hot, heavy LED assembly off the carriage and away
from the Pi~5 / Hailo-8 thermal budget; only the collimator tip travels behind
the chip currently in view.

The source is adapted from the mirror-based ModLight design~\cite{Gibson2023},
an open-hardware (CC~BY-SA-4.0) modular LED light source that delivers a
collimated beam through a light guide and has been demonstrated directly on
OpenFlexure. The mirror variant is chosen over the X-Cube-prism variant because
it reaches the near-infrared and because the step-and-image acquisition images
one channel at a time, so the prism's simultaneous wavelength mixing is not
needed. The target application---monitoring \emph{calcification} in the cultured
cells---drives the channel selection: calcium deposits stained with Alizarin
Red~S form a red complex absorbing around \SIrange{528}{560}{\nano\meter}, so a
green channel (\SIrange{525}{530}{\nano\meter}) maximises their brightfield
contrast; a white channel serves overview and von-Kossa-stained (dark) deposits;
and a near-infrared channel penetrates the thick, turbid chip with less
scattering and provides a label-free scattering signal from the birefringent
hydroxyapatite nodules. Switching the mirror between channels is manual
(magnet-held) in the published design, which is acceptable for per-scan channel
selection in the prototype; motorising it is a later option. \todo{specify the
final per-channel centre wavelengths, diffuser and irradiance once the
illumination hardware is built and measured.}

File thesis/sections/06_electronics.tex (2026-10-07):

\section{Electronics and Motion Control}
\label{sec:electronics}

\subsection{Compute stack}
The compute stack is a Raspberry~Pi~5 (\SI{8}{\giga\byte}) with the AI~HAT+
(Hailo-8, \SI{26}{TOPS}) on the PCIe interface and a DS3231 real-time clock on
the GPIO header for time-stamping unattended runs. The Hailo driver requires a
DKMS rebuild and a reboot in a specific order (Section~\ref{sec:software}).
The three boards stack inside the pull-out electronics drawer
(Fig.~\ref{fig:drawer}).

\begin{figure}[!t]
  \centering
  \figorplaceholder{exploded_drawer_nolabels.png}{0.8\columnwidth}
  \caption{Exploded view of the electronics drawer and its compute stack: the
  printed pull-out drawer carries, from bottom to top, the Raspberry~Pi~5, the
  AI~HAT+ (Hailo-8) and the Sangaboard motor-controller. Rendered with OpenSCAD
  from \texttt{hardware/assembly/openscad/exploded\_drawer.scad}; the boards are
  simplified placeholder solids.}
  \label{fig:drawer}
\end{figure}

\subsection{Focus axis}
The Z-focus axis is driven by a 28BYJ-48 5\,V geared stepper through the
Sangaboard's on-board ULN2003 channel, as in the stock OpenFlexure Z actuator.
Two further 28BYJ-48 motors from the original XYZ plan are on hand as spares.

\subsection{Rail axis}
The linear rail is driven by a NEMA17 stepper with an integrated Tr8$\times$2
leadscrew via a TMC2209 stepstick, with an anti-backlash nut, a coupler and an
end bearing. This axis carries the imaging head between chip stations.

\subsection{Stage driver architecture}
Motion control follows a \emph{hybrid} architecture, decided on
2026-09-03. The Sangaboard is retained for the two tasks it already supports
natively out of the box, namely the focus stepper and the illumination LED (PWM
dimming), so no bare-GPIO focus or LED driver has to be written. The new linear
rail, which the Sangaboard's ULN2003 channels cannot drive, runs on a
standalone TMC2209 stepstick wired to the Pi~5 GPIO (step/dir/enable) and
sequenced from Python. The Sangaboard's now-unused X/Y outputs are left
unconnected, since the tilted geometry makes the original sample-stage axes
functionless (Section~\ref{sec:mechanical}).

\subsection{Illumination driver}
Illumination uses the fibre-coupled mirror-based ModLight source
(Section~\ref{sec:optical}). Because that variant drives one LED channel at a
time, the existing Sangaboard PWM illumination output is retained to power and
dim the active channel---no dedicated driver board is required. The dedicated
ModLight LED controller (Gerber and schematic in
\texttt{sources/modlight/Electronics}) becomes necessary only if simultaneous
multi-channel operation is later adopted; it is kept as a documented fallback.

\subsection{Power budget}
The Pi~5 stack runs from a \SI{27}{\watt} USB-C supply; the rail axis needs a
separate \SIrange{12}{24}{\volt}, $\geq\SI{2}{\ampere}$ supply for the NEMA17 /
TMC2209. \todo{measure the full power budget (idle, imaging, inference,
slewing).}

\subsection{Wiring}
\todo{provide the full wiring diagram (GPIO pin map, ULN2003 and TMC2209
connections, end-stop switches, illumination) in Appendix~\ref{sec:appendix}.}

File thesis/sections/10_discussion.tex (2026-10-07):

\section{Discussion}
\label{sec:discussion}

\subsection{Meeting the requirements}
The design meets the cost target (RQ1/NFR1) with headroom: $\approx\num{443}$~EUR
for the full head-plus-rail system against a \num{500}~EUR budget, and it is
built entirely from open hardware and 3D-printed parts, reproducible via Ansible
(NFR2). On-device inference on the Pi~5 + Hailo-8 keeps all compute on the
instrument (NFR3). The remaining requirements---per-chip autofocus, repeatable
translation, unattended incubator operation and the detection accuracy
target---depend on hardware and model work that is not yet complete and are
tracked as milestones M1--M3.

\subsection{Design trade-offs}
Replacing the OpenFlexure XY flexure stage with a horizontal tilt plus an
external linear rail trades planar sample scanning for serial multi-chip
scanning, which matches the perfused-bioreactor use case (one head visiting
several chips) better than a single-sample XY stage. It also simplifies the
printed body to a Z-focus-only part. The cost is a larger mechanical envelope
(rail, carriage, NEMA17) and a new motion-control path that no longer uses the
stock Sangaboard.

\subsection{Open decisions}
Several parameters are deliberately left open and marked in the text:
\begin{itemize}
\item the objective tube-length marking and thread (finite $160$ / RMS vs.\
  $\infty$ ICS / M27), which sets the exact magnification and object-space
  sampling (Section~\ref{sec:optical}, M1);
\item the stage driver architecture---all-Python GPIO versus a Sangaboard-hybrid
  (Section~\ref{sec:electronics}, M2);
\item the biological readout and hence the detector family and CVAT label schema
  (Section~\ref{sec:edgeai}, M1);
\item the chip pitch and rack geometry against the physical chips
  (Section~\ref{sec:mechanical}, M3).
\end{itemize}
The repository documentation is currently inconsistent on the IMX477 sensor size
and the system magnification; these are reconciled in
\texttt{docs/THESIS\_PARAMETER\_GAPS.md} and must be fixed before the optical
budget is finalised.

\subsection{Limitations}
The evaluation is at present a design and cost evaluation; the biological
validation (detection accuracy, unattended runs) is future work. The
fibre-coupled illumination is not yet characterised per channel (wavelength,
diffuser, irradiance), and the
full power budget under imaging, inference and slewing has not been measured.

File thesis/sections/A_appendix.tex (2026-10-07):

\section{Printed Parts and Print Settings}
\label{sec:appendix}

All parts print in PLA (optical parts in black to suppress stray light) at
\SI{0.2}{\milli\meter} layer height (\SI{0.15}{\milli\meter} for the optics
module), \SI{0.4}{\milli\meter} nozzle, three perimeters and
\SIrange{20}{30}{\percent} infill. A brim is recommended for the main body. The
canonical, per-part checklist is \texttt{hardware/PRINT\_CHECKLIST.md};
Table~\ref{tab:printed} lists the custom and must-print parts.

\begin{table}[!t]
  \centering
  \caption{Key printed parts (custom mesoscope parts and must-print OpenFlexure
  parts). Masses and print times are per-part; the main body mass is measured,
  the remainder are to be filled from the slicer.}
  \label{tab:printed}
  \begin{tabular}{@{}llc@{}}
    \toprule
    Part & Role & Mass \\
    \midrule
    \texttt{main\_body\_mesoscope.stl}        & Z-focus-only body & $\approx\SI{65}{\gram}$ \\
    \texttt{optics\_hq\_125\_rms.stl}         & C-mount optics (125\,mm) & \todo{} \\
    \texttt{optics\_hq\_150\_rms.stl}         & C-mount optics (150\,mm) & \todo{} \\
    \texttt{microscope\_stand\_mesoscope.stl} & Stand & \todo{} \\
    \texttt{electronics\_drawer\_mesoscope.stl} & Pi5/AI-HAT drawer & \todo{} \\
    \texttt{bioreactor\_rack\_n\textit{N}.stl} & $N$-chip rack & \todo{} \\
    \texttt{large\_gears.stl}                 & Z actuation & \todo{} \\
    ModLight fibre source                     & Trans-illumination (\S\ref{sec:optical}) & \todo{} \\
    \texttt{feet.stl}                         & Feet & \todo{} \\
    \bottomrule
  \end{tabular}
\end{table}

The stock OpenFlexure illumination housing (\texttt{condenser.stl} and the
dovetail arm) is no longer used: it cannot clear the \SI{16}{\milli\meter} chip
and is replaced by the fibre-coupled ModLight source~\cite{Gibson2023}
(\S\ref{sec:optical}), whose design files are mirrored under
\texttt{sources/modlight/} (the OpenFlexure-adapted \texttt{Condenser\_Holder}
and \texttt{Fibre\_Holder} are provided as STL only; the mirror source housing
and common fibre parts also ship as OpenSCAD and STEP).

\todo{fill in the per-part masses, volumes and print times from the slicer for
all parts, and add the rail-mount and carriage parts once
\texttt{rail\_mount\_mesoscope.scad} is finalised.}

\section{Wiring and Pin Map}
\label{sec:wiring}
\todo{provide the full wiring diagram: Raspberry~Pi~5 GPIO pin map, ULN2003
(focus 28BYJ-48) and TMC2209 (rail NEMA17, step/dir) connections, end-stop
switches and the Sangaboard-PWM illumination channel, plus the two power supplies
(\SI{27}{\watt} USB-C for the Pi stack; \SIrange{12}{24}{\volt},
$\geq\SI{2}{\ampere}$ for the rail).}

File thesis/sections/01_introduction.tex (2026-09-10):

\section{Introduction}
\label{sec:introduction}

\IEEEPARstart{C}{ontinuous}, non-destructive observation of adherent cell
cultures inside perfused bioreactor chips---for example hFOB~1.19 osteoblasts
and hMEC~1 endothelial cells under pressure and flow test series---is a
recurring need in tissue-engineering and mechanobiology experiments. Today it is
served either by \emph{manual microscopy}, which removes the chip from the
incubator, is operator-dependent and offers low temporal resolution, or by
\emph{commercial live-cell imagers}, which are expensive, closed and typically
observe a single vessel at a time.

This thesis designs, builds and validates \emph{IDANA}, a mesoscope: an
OpenFlexure-derived microscope running on a Raspberry~Pi~5 with a Hailo-8
neural-processing unit (NPU) and a Pi High-Quality (HQ) camera. The microscope
is laid horizontally and mounted on a linear rail so that a single imaging head
scans a rack of bioreactor chips in series, and it evaluates cell-level images
on-device without external compute infrastructure.

\subsection{Problem statement}
The core problem is to observe several perfused bioreactor chips repeatedly,
inside the incubator, through their small optical windows, at a spatial and
temporal resolution adequate for automated cell analysis, at a cost far below
commercial live-cell imaging systems.

\subsection{Research questions}
\begin{itemize}
\item \textbf{RQ1 (System).} Can an open-source, sub-\num{500}~EUR
  microscope built from OpenFlexure, a Pi HQ camera and 3D-printed parts deliver
  image quality (resolution, field of view, focus stability) sufficient for
  automated cell analysis in a bioreactor chip through its observation window?
\item \textbf{RQ2 (Automation).} Can a single imaging head on a linear X-rail
  revisit $N$ bioreactors autonomously with positioning repeatability and
  autofocus reliability adequate for time-lapse monitoring over days inside an
  incubator?
\item \textbf{RQ3 (Edge AI).} Can a cell-detection/segmentation model trained on
  data annotated in CVAT be deployed on the Hailo-8 NPU with accuracy
  (mAP / IoU / count error) and throughput sufficient for on-device,
  near-real-time analysis---and how does it compare to inference on the Pi CPU
  and to manual counting?
\end{itemize}

\subsection{Hypotheses and success criteria}
\label{sec:hypotheses}
The following criteria are the current targets; they are finalised in
milestone~M1 (see Section~\ref{sec:evaluation}).
\begin{itemize}
\item \textbf{H1.} Measured lateral resolution $\leq \SI{1.5}{\micro\meter}$
  (USAF~1951 target; Rayleigh limit $\approx \SI{1.1}{\micro\meter}$ at
  NA~$0.30$) and field of view $\geq \SI{0.5}{\milli\meter\squared}$ with the
  ZEISS Plan-Neofluar $10\times/0.30$ objective and a \SI{125}{\milli\meter}
  tube lens.
\item \textbf{H2.} Rail positioning repeatability
  $\leq \pm\SI{10}{\micro\meter}$; autofocus success rate $\geq \SI{95}{\percent}$
  across $\geq 3$ chips over \SI{72}{\hour}.
\item \textbf{H3.} Cell-detection mAP@0.5 $\geq 0.8$ on held-out chips; Hailo-8
  inference $\geq 10\times$ faster than the Pi CPU at equal accuracy
  ($\pm\SI{2}{\percent}$ mAP).
\end{itemize}

\subsection{Contributions}
\label{sec:contributions}
\begin{enumerate}
\item A reproducible port of the OpenFlexure Server~v3 to Raspberry~Pi~5 /
  Trixie via Ansible, including documented fixes for the Pi~5 image-signal
  processor (ISP), camera stack and Hailo driver.
\item A C-mount HQ-camera optics module with a \SI{125}{\milli\meter} (and
  \SI{150}{\milli\meter}) tube lens for the IMX477 sensor, with full optical
  derivation and printable CAD.
\item A tilted, rail-mounted imaging head with a Z-focus-only body and a
  parametric bioreactor rack---a new form factor for serial monitoring of
  multiple chips.
\item An all-Python GPIO stage driver (focus stepper + rail stepper) replacing
  the Sangaboard microcontroller. \todo{confirm motor architecture, milestone
  M2.}
\item A CVAT-annotated cell dataset from bioreactor-chip images and a
  Hailo-8-deployed detection model with a CPU-versus-NPU evaluation.
\item Quantitative validation of the complete system against the stated
  requirements.
\end{enumerate}

\subsection{Thesis structure}
Section~\ref{sec:background} surveys live-cell imaging, open-hardware microscopy
and edge AI. Section~\ref{sec:requirements} derives requirements and the system
concept. Sections~\ref{sec:optical}--\ref{sec:software} present the optical,
mechanical, electronic and software design. Section~\ref{sec:edgeai} describes
the edge-AI pipeline. Section~\ref{sec:evaluation} evaluates the system,
Section~\ref{sec:discussion} answers RQ1--RQ3, and
Section~\ref{sec:conclusion} concludes.

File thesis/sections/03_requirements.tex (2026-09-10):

\section{Requirements and System Concept}
\label{sec:requirements}

\subsection{Use case}
A rack holds $N$ perfused bioreactor chips in series inside an incubator. One
imaging head, tilted so its optical axis is horizontal, translates along a
linear X-rail, stops at each chip, focuses through the chip's optical window,
acquires an image (or Z-stack), and runs on-device inference before moving to
the next chip. Acquisition repeats on a schedule over hours to days.

\subsection{Functional requirements}
\begin{itemize}
\item FR1: image each of $N$ chips through its
  $18\times\SI{8}{\milli\meter}$ window.
\item FR2: autofocus per chip via the Z-focus axis.
\item FR3: translate between chips and stop repeatably at each station.
\item FR4: acquire and store time-stamped images with metadata.
\item FR5: run cell detection on-device and log per-chip results.
\item FR6: operate unattended inside an incubator on a fixed schedule.
\end{itemize}

\subsection{Non-functional requirements}
\begin{itemize}
\item NFR1: total parts cost $< \num{500}$~EUR (RQ1).
\item NFR2: built from open hardware and 3D-printed parts; reproducible via
  Ansible.
\item NFR3: no external compute; inference on the Pi~5 + Hailo-8.
\item NFR4: tolerant of the incubator environment (\SI{37}{\celsius}, high
  humidity). \todo{define environmental qualification.}
\end{itemize}

\subsection{Architecture overview}
The system comprises (i) the imaging head---HQ camera, C-mount optics module,
ZEISS objective and Z-focus body; (ii) the motion system---horizontal tilt
mount, V-slot rail, carriage and rail stepper; (iii) the compute stack---Pi~5,
AI~HAT+ (Hailo-8), RTC; and (iv) the software---OpenFlexure Server~v3, the
Ansible provisioning, the scan/time-lapse orchestration and the CVAT annotation
server on a separate VPS. The high-level block diagram is given in the project
\texttt{README.md}; Sections~\ref{sec:optical}--\ref{sec:software} detail each
subsystem.

\subsection{Key design decisions}
\begin{itemize}
\item \emph{Pi~5 + Hailo-8} rather than a Pi~3/4 without NPU: enables on-device
  inference at the cost of an $\approx\num{150}$~EUR premium
  (Section~\ref{sec:evaluation}, Table~\ref{tab:cost}).
\item \emph{OpenFlexure v3} (FastAPI, Python~$\geq 3.11$) rather than the legacy
  v2 server.
\item \emph{Horizontal tilt + linear rail} rather than an XY flexure stage:
  trades lateral flexure motion for multi-chip serial scanning.
\item \emph{Z-focus-only body}: the XY flexure of the stock OpenFlexure body is
  removed, simplifying the print and freeing the sample plane for the rail.
\end{itemize}
See \texttt{docs/RAIL\_MOUNT\_CONCEPT.md} for the rail concept rationale.

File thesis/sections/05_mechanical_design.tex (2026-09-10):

\section{Mechanical Design}
\label{sec:mechanical}

\subsection{Z-focus-only body}
The imaging head uses a modified OpenFlexure main body with only the Z (focus)
flexure retained; the XY lateral flexure is removed, since lateral motion is
provided by the external rail. The body is printed in PLA
(\texttt{main\_body\_mesoscope.stl}, $\approx\SI{65}{\gram}$) and drives the
optics module along the optical axis via the standard actuator column.

\subsection{Stand and electronics drawer}
A printed stand holds the body and carries a pull-out electronics drawer sized
for the Pi~5, the AI~HAT+ and the RTC (\texttt{microscope\_stand\_mesoscope.stl},
\texttt{electronics\_drawer\_mesoscope.stl}). Board heights and clearances are
documented in \texttt{hardware/stand/openscad/microscope\_stand\_readme.md}.

\subsection{Horizontal tilt and linear rail}
For serial scanning, the whole microscope is tilted \SI{90}{\degree} onto its
side so the optical axis becomes horizontal, resting on the Z-axis motor face.
It is mounted on a carriage on a 2040 V-slot / MGN12 linear rail oriented
perpendicular to the optical path; a bioreactor rack carries the chips in series
on the same structure. A separate rail stepper moves the carriage from chip to
chip (Section~\ref{sec:electronics}). The rail-mount geometry is parametric in
\texttt{hardware/mount/openscad/rail\_mount\_mesoscope.scad}.

\subsection{Bioreactor rack}
A parametric, standalone rack (\texttt{bioreactor\_rack.scad}; renders to
\texttt{bioreactor\_rack\_n\textit{N}.stl}) holds $N$ chips at a fixed pitch.
\todo{confirm the chip pitch (\SI{80}{\milli\meter} assumed) and the rack
geometry against the physical chips, milestone~M3.}

\subsection{Exploded view}
Fig.~\ref{fig:exploded} shows the exploded upright stack, rendered from the CAD
sources in \texttt{hardware/assembly/} (run \texttt{build\_exploded.sh}; the PNGs
are not committed). Front, opposite-side and unlabelled variants are available.

\begin{figure}[!t]
  \centering
  % rendered by hardware/assembly/build_exploded.sh (not committed to git)
  \figorplaceholder{exploded_view_nolabels.png}{\columnwidth}
  \caption{Exploded view of the upright mesoscope stack: stand and electronics
  drawer, Z-focus body, Z actuator and motor, HQ-camera optics module,
  objective, sample/bioreactor chip and illumination. Rendered with OpenSCAD
  from \texttt{hardware/assembly/openscad/exploded\_view.scad}. Some PCBs, the
  camera, the chip and the LED are simplified placeholder solids.}
  \label{fig:exploded}
\end{figure}

\subsection{Print parameters and tolerances}
Parts print in PLA at \SI{0.2}{\milli\meter} layer height, three perimeters and
\SIrange{20}{30}{\percent} infill. Per-part masses, volumes and print times are
listed in Table~\ref{tab:printed} (Appendix~\ref{sec:appendix}); the print
checklist is in \texttt{hardware/PRINT\_CHECKLIST.md}.

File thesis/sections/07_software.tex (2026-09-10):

\section{Software and Provisioning}
\label{sec:software}

\subsection{OpenFlexure Server v3}
The imaging head runs OpenFlexure Server~v3 (FastAPI, Python~$\geq 3.11$). The
server is installed from the upstream \texttt{v3} branch into a
\texttt{--system-site-packages} virtual environment so that it can reuse the
apt-installed \texttt{picamera2} and \texttt{libcamera} stack; the web frontend
is pulled as a prebuilt CI artifact rather than built locally. Camera and stage
selection are driven by a configuration template
(\texttt{ofm\_config.json.j2} $\rightarrow$
\texttt{/var/openflexure/settings/ofm\_config.json}), which selects the HQ
Camera and the stage backend without modifying the server itself.

\subsection{Raspberry Pi 5 integration}
Running the OpenFlexure stack on the Pi~5 required several platform-specific
fixes that are encoded in the provisioning rather than applied by hand:
\begin{itemize}
\item the Hailo-8 driver needs a DKMS rebuild followed by a reboot in a fixed
  order before the NPU enumerates on PCIe;
\item the camera pipeline needs a pisp ISP tuning patch, PipeWire masking and
  a systemd \texttt{SupplementaryGroups} entry so the service can access the
  camera device;
\item the HQ-camera image is vertically flipped on the Pi~5 to match the
  physical orientation.
\end{itemize}
The tested camera white balance for the current illumination is an exposure of
\SI{492}{\micro\second}, analogue gain \num{1.0} and colour gains
$[0.9,\,2.9]$ (red, blue), which resolves the earlier red cast of the IMX477.

\subsection{Ansible provisioning}
The whole system is reproducible via Ansible from two entry points with
separate inventories. \texttt{site.yml} targets the Pi~5 and runs the roles
\texttt{base} $\rightarrow$ \texttt{ai-hat} $\rightarrow$ \texttt{openflexure}
$\rightarrow$ \texttt{motor-controller} in order; the motor-controller role is
skipped until the stage hardware is connected. \texttt{cvat.yml} and
\texttt{users.yml} target a separate VPS and deploy the CVAT annotation server
(Docker) behind a Caddy reverse proxy with automatic HTTPS. This satisfies the
reproducibility requirement NFR2 (Section~\ref{sec:requirements}).

\subsection{Acquisition orchestration}
Unattended operation is scheduled scan/time-lapse orchestration on top of the
OpenFlexure API: for each chip the head slews to the station, autofocuses on the
Z-axis, acquires an image or Z-stack, runs on-device inference
(Section~\ref{sec:edgeai}) and writes time-stamped images with metadata using
the DS3231 RTC for a reliable clock. \todo{document the orchestration script and
its schedule format once the rail stage is driving real hardware
(milestone~M2).}

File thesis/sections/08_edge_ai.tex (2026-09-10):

\section{On-Device Cell Detection}
\label{sec:edgeai}

\subsection{Inference target}
On-device inference keeps images on the instrument and enables near-real-time
analysis inside the incubator (NFR3). The target accelerator is the Hailo-8 NPU
(\SI{26}{TOPS}) on the AI~HAT+; models must be compiled to the Hailo Executable
Format (HEF) with the Hailo Dataflow Compiler and quantised to integer
precision to run on the device.

\subsection{Model choice}
The biological readout---confluence, count, morphology or migration---fixes both
the model family and the CVAT label schema, and is an open decision (milestone
M1, Section~\ref{sec:requirements}). Bounding-box detection (YOLOv8 and
variants) suffices for counting and confluence, whereas instance segmentation
(Cellpose~\cite{Stringer2021Cellpose}, StarDist~\cite{Schmidt2018StarDist})
is required for per-cell morphology. Only a foreign YOLOv8s-Pose benchmark
currently exists in the project; the task-specific model is future work.
\todo{fix the readout and label schema (M1), then train and compile the
task-specific detector to HEF; report accuracy and on-device latency.}

\subsection{Annotation pipeline}
Training data are annotated in a CVAT server deployed on a separate VPS
(Section~\ref{sec:software}). Acquired chip images are uploaded, labelled
according to the chosen schema, exported and used to train the detector, which
is then quantised and compiled for the Hailo-8. \todo{describe the dataset size,
train/val split and augmentation once acquisition on real chips has started.}

\subsection{Evaluation plan}
The detector will be evaluated both offline (detection metrics on a held-out
set) and on-device (end-to-end latency and throughput per chip on the Pi~5 +
Hailo-8), so that the imaging schedule can be sized against the per-chip
inference time. Results are reported in Section~\ref{sec:evaluation} once the
model exists.

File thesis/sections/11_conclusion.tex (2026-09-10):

\section{Conclusion and Future Work}
\label{sec:conclusion}

\subsection{Conclusion}
This thesis presented the mesoscope, a low-cost automated microscope for
imaging perfused bioreactor chips inside an incubator. It reuses the OpenFlexure
optics and Z-focus mechanics but replaces the XY flexure stage with a horizontal
tilt and an external linear rail, so that a single imaging head can serially
visit $N$ chips. Compute and inference run on-device on a Raspberry~Pi~5 with a
Hailo-8 NPU, and the whole software stack is reproducible via Ansible. The parts
cost of the full head-plus-rail system is $\approx\num{443}$~EUR, meeting the
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

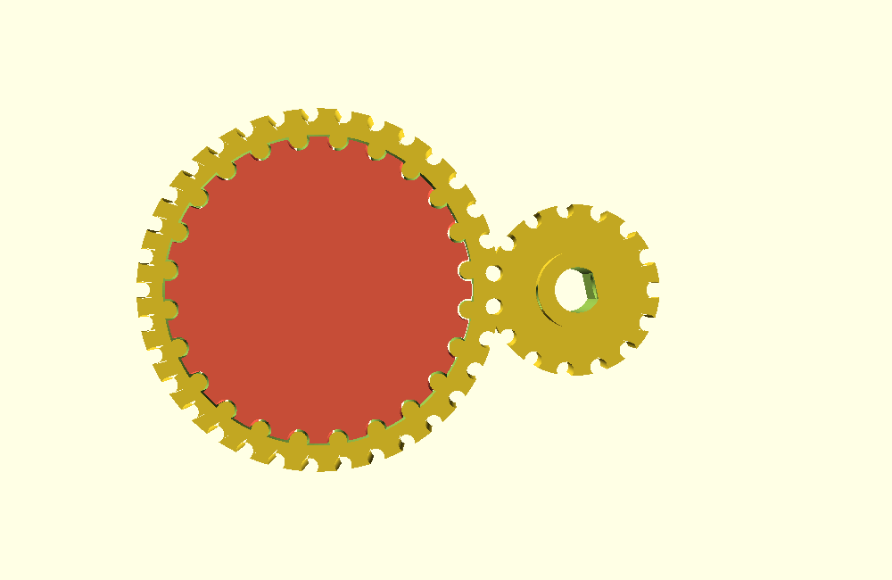
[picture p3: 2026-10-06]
hardware/gears/openscad/gear_pair_preview.png

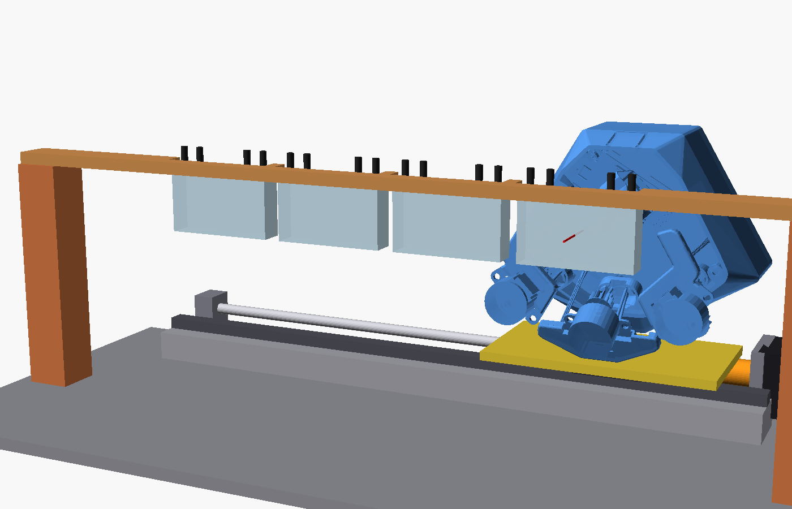
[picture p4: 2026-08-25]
hardware/mount/openscad/rail_mount_top.png

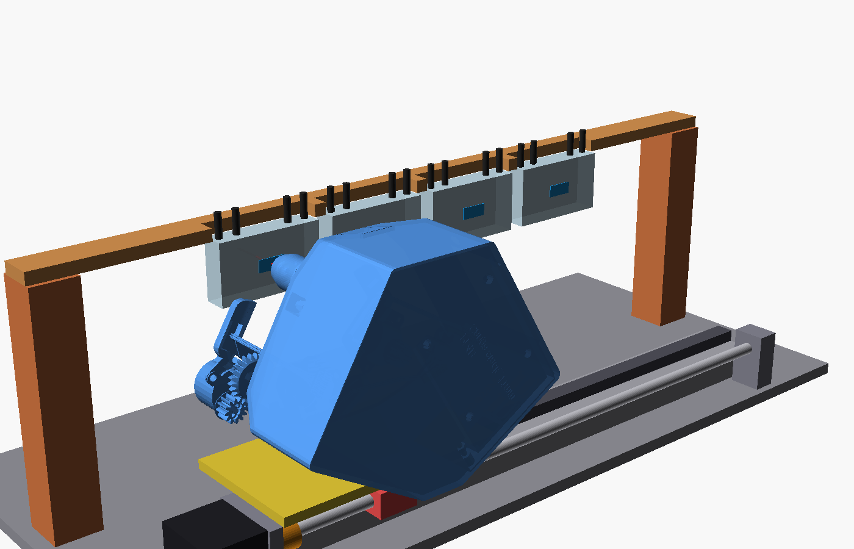
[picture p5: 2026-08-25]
hardware/mount/openscad/rail_mount_preview.png

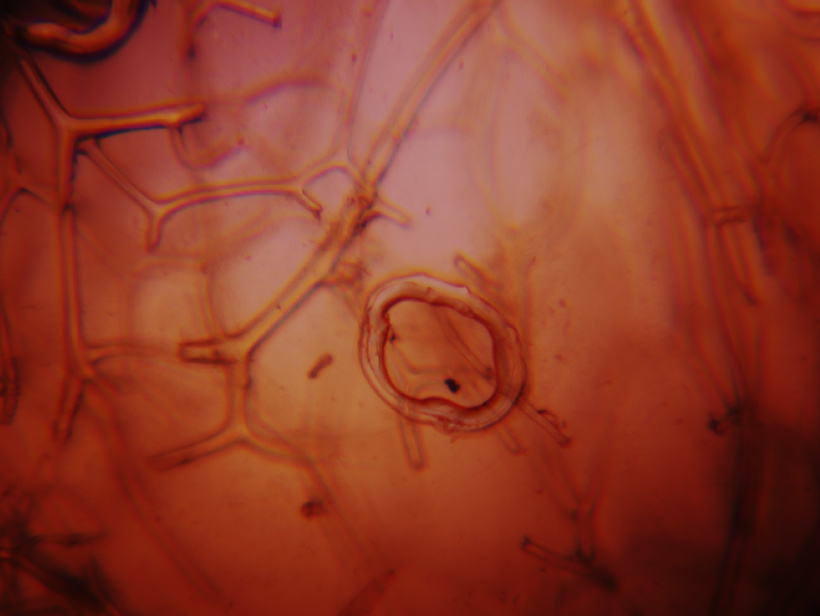
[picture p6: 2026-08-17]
resources/OFM_2026-08-17T14_51_24.609Z.jpeg

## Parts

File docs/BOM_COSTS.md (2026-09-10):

# Bill of Materials & Cost Comparison

State: 2026-09-08. All prices **EUR incl. VAT** unless noted. Column *Price basis*:
**est.** = estimate from `README.md` BOM (no invoice in repo) · **market** = typical used/new
market price · **TODO** = enter actual invoice value. Replace estimates with invoice values
before the thesis (appendix A).

## A. Mesoscope — parts actually installed / on hand

### A.1 Compute & control

| # | Part | Qty | Unit € | Line € | Price basis | Status |
|---|---|-----|---|---|---|---|
| 1 | Raspberry Pi 5, 8 GB | 1 | 80 | 80 | est. | installed |
| 2 | Raspberry Pi AI HAT+ (Hailo-8, 26 TOPS) | 1 | 70 | 70 | est. | installed |
| 3 | DS3231 RTC module | 1 | 5 | 5 | est. | installed |
| 4 | GPIO stacking header (RTC pass-through) | 1 | 3 | 3 | est. | installed |
| 5 | microSD ≥ 32 GB (117 GB used in profile → 128 GB) | 1 | 10 | 10 | est. | installed |
| 6 | USB-C PSU 27 W (official) | 1 | 15 | 15 | est. | installed |
| 7 | 28BYJ-48 stepper, 5 V (Z-focus; 2 spare from original XYZ plan) | 3 | 2 | 6 | est. | on hand |
| 8 | ULN2003 driver board (bundled with 28BYJ-48) | 3 | 1 | 3 | est. | on hand |
| 9 | TMC2209 stepstick (rail axis) | 1 (+spares) | 4 | 4 | market | on hand |
| | **Subtotal compute & control** | | | **196** | | |

### A.2 Optics & imaging

| # | Part | Qty | Unit € | Line € | Price basis | Status |
|---|---|-----|---|---|---|---|
| 10 | Raspberry Pi HQ Camera (IMX477, C-mount) | 1 | 35 | 35 | est. | installed |
| 11 | **ZEISS Plan-Neofluar 10×/0.30** objective | 1 | 0 (owned) / 150–350 | 0 | market (used); TODO if purchased | installed |
| 12 | Achromatic doublet tube lens f = 125 mm, Ø12.7 mm (Taulab, 2026-06-22) | 1 | 25 | 25 | TODO (invoice) | installed |
| 13 | Achromatic doublet tube lens f = 150 mm, Ø12.7 mm (Taulab, 2026-06-22) | 1 | 25 | 25 | TODO (invoice) | spare |
| 14 | PMMA condenser lens Ø13 mm f = 5 mm + LED (stock OFM illumination) | 1 | 3 | 3 | est. | not used in rail concept |
| | **Subtotal optics** (objective at 0) | | | **88** | | |
| | *Subtotal optics with objective at market value (250)* | | | *(338)* | | |

### A.3 Printed parts (PLA black, 0.2 mm, 3 walls, 20–30 % infill)

Mass estimated as solid STL volume × 1.24 g/cm³ × 0.6 (wall/infill factor); filament at 25 €/kg.
Print times from the `.bgcode` filenames in `hardware/gcode/` where available.

| # | Part (STL) | Solid vol. cm³ | ≈ mass g | ≈ € | Print time | Status |
|---|---|---:|---:|----:|---|---|
| 15 | `main_body_mesoscope.stl` (Z-only body) | 87.6 | 65 | 1.6 | — | STL, test print pending |
| 16 | `optics_hq_125_rms_threaded.stl` | 28.5 | 21 | 0.5 | 1 h 07 (PETG) | printed |
| 17 | `microscope_stand_mesoscope.stl` | 122.7 | 91 | 2.3 | — | STL |
| 18 | `electronics_drawer_mesoscope.stl` | 35.1 | 26 | 0.7 | 4 h 12 | printed |
| 19 | `feet.stl` | 6.0 | 4 | 0.1 | — | STL |
| 20 | `large_gears.stl` + `small_gears.stl` | 12.3 | 9 | 0.2 | — | STL |
| 21 | `picamera_hq_cover.stl` | 2.1 | 2 | 0.1 | — | STL |
| 22 | `bioreactor_rack_n3.stl` (rail concept) | 305.3 | 227 | 5.7 | — | STL, geometry unconfirmed |
| 23 | tools (`actuator_assembly_tools`, `lens_tool`, `cable_tidies`) | 20.7 | 15 | 0.4 | — | STL |
| | **Subtotal printed** (≈ 460 g) | | | **≈ 12** | | |

### A.4 Fasteners & consumables (OFM standard)

| # | Part | Qty | Line € | Price basis |
|---|---|-----|---|---|
| 24 | M3 screws/nuts, M3×25 hex-head actuator screws, M2 camera screws | set | 5 | est. |
| 25 | Viton O-rings (actuator preload) | 3 | 3 | est. |
| 26 | LED 5 mm + resistor, wire | 1 | 2 | est. |
| | **Subtotal** | | **10** | |

### A.5 Totals — microscope as currently built (no rail)

| Scope | € |
|---|---|
| Compute & control (A.1) | 196 |
| Optics, objective owned (A.2) | 88 |
| Printed parts (A.3) | 12 |
| Fasteners (A.4) | 10 |
| **Total, objective owned** | **≈ 306** |
| of which "microscope only" (without Pi 5 + AI HAT + RTC + SD + PSU: −183) | ≈ 123 |
| **Total incl. objective at market value (250)** | **≈ 556** |

> The Pi 5 + AI HAT+ stack (≈ 150 €) is the price of on-device inference; the
> OpenFlexure reference designs use a Pi 3/4 without NPU (see §C).

## B. Rail mount — planned, not yet purchased (`docs/RAIL_MOUNT_CONCEPT.md` §7, decided 2026-09-02)

| # | Part | Qty | Unit € | Line € | Price basis |
|---|---|-----|---|---|---|
| 27 | 2040 V-slot aluminium extrusion, ≈ 500 mm | 1 | 12 | 12 | market |
| 28 | MGN12H linear rail 400–500 mm + carriage | 1 | 25 | 25 | market |
| 29 | NEMA17 with integrated Tr8×2 leadscrew (≈ 400 mm), ≤ 1.5 A | 1 | 25 | 25 | market |
| 30 | Anti-backlash nut (Tr8×2) + KFL08 end bearing + coupler | 1 set | 10 | 10 | market |
| 31 | 12–24 V PSU ≥ 2 A | 1 | 15 | 15 | market |
| 32 | Base plate (Grundplatte), bridge board, pillars (plywood/aluminium) | 1 set | 20 | 20 | est. |
| 33 | Carriage adapter + tilt mount (printed, ≈ 150 g) | 1 | 4 | 4 | est. |
| 34 | Trans-illumination LED panel/diffuser per station | 3–4 | 4 | 16 | est. |
| 35 | Cables, terminals, 100 µF caps, end-stop switches | set | 10 | 10 | est. |
| | **Subtotal rail mount** | | | **≈ 137** | |

**Full system (A + B), objective owned: ≈ 443 €** — inside the < 500 € target of RQ1.

## C. OpenFlexure project reference BOMs (published prices)

Research date 2026-09-08. The official v7 BOM pages list **items and quantities only, no
prices**; prices come from the project's papers and from kit vendors.

### C.1 Official v7 BOM (v7.0.0-beta1, build.openflexure.org) — items, no prices

| Category | Item | Low-cost | High-res |
|---|---|:---:|:---:|
| Printed | PLA filament (any colour) | 205 g | 205 g |
| Printed | Black PLA (optics) | 50 g | 50 g |
| Material | 0.5 mm polypropylene sheet | 4 cm² | 4 cm² |
| Optics | Condenser lens f = 5 mm | 1 | 1 |
| Optics | Ø12.7 mm achromatic doublet (tube lens) | – | 1 |
| Optics | RMS objective, 160 mm finite | – | 1 |
| Electronics | Raspberry Pi 3B/3B+/4B | 1 | 1 |
| Electronics | Pi Camera Module v2 | 1 | 1 |
| Electronics | 200 mm camera ribbon | 1 | 1 |
| Electronics | Pi PSU | 1 | 1 |
| Electronics | Sangaboard v0.5 | 1 | 1 |
| Electronics | 28BYJ-48 geared stepper | 3 | 3 |
| Electronics | Illumination PCB + 2× 2-pin DuPont | 1 | 1 |
| Mechanical | M3 brass nut 3; M3 SS nut 14; M3 washer 8; M3×10 cap 11; M3×25 hex 4; M4×6 button 6; No.2×6.5 self-tap 16–18; Viton O-ring 30×2 3 | set | set |

The Delta Stage BOM is analogous (1 Sangaboard, 3 motors, condenser, objective, tube lens,
3 rubber feet; 16–19 h print, ~18 % infill), no prices. The `hq_camera` GitLab branch has
**no separate BOM or cost documentation**.

### C.2 Project cost estimates (Collins et al. 2020, Biomed. Opt. Express 11(5):2447, SI; UK retail Dec 2019, 1 GBP = 1.30 USD)

| Variant | Itemisation | Total (one-off) |
|---|---|---|
| Low-cost (webcam, no Pi, no motors) | PLA $5, webcam $5, hardware $26 | ≈ **$36** |
| Basic (Pi + Pi Cam, no motors) | PLA $5, Pi $35, Pi Cam v2.1 $25, hardware $26 | ≈ **$91** |
| High-res motorised | PLA $5, Pi $35, Pi Cam $25, hardware $26, 3× 28BYJ-48 $5, achromat $55, RMS objective $50, motor board $50 | ≈ **$251** (bulk hardware ≈ $230) |

Fastener detail (GBP unit/pack): M3×25 hex 0.104/3.12 (×3), M3 brass nut 0.049/2.45 (×4),
M3 washer 0.009/1.80 (×8), M3×8 cap 0.035/2.80 (×14), M2×6 cap 0.11/3.30 (×4), Viton O-ring
0.56/2.80 (×3), 5 mm LED 0.23, 60 Ω resistor 0.03/0.30, M4×6 button 0.06/2.40 (×6) — bulk
total £3.80, one-off £19.20. Assembly 3–4 h novice / 1–2 h experienced; printer excluded.

Later project statements: "around £200 in parts" for the motorised high-res version (MMC
2021); "~$300 to build in the lab" (Knapper, *The Pathologist*, 2024-03); IO Rodeo measured
**$305** for a v7 high-res build (blog 2024-03-20).

### C.3 Kit vendor prices (live 2026-09-08)

| Vendor | Product | Price | Includes | Excludes |
|---|---|---|---|---|
| IO Rodeo (US) | Microscope Kit (printed parts + assembly kit) | **$200** | printed parts, Sangaboard v5, 3 motors, Pi Cam v2, illumination, condenser, hardware | Pi, PSU, objective + tube lens |
| IO Rodeo | Assembly Kit (no printed parts) | **$148** | Pi Cam v2, Sangaboard v0.5, 3 motors, 64 GB SD, condenser, illumination, hardware, oil, Allen key | Pi, PSU, high-res optics |
| LabCrafter (UK) | Microscope Kit (low-cost v7) | **£160** (sold out) | Sangaboard v5, motors, Pi Cam v2, illumination, hardware, tools | Pi, PSU, SD |
| LabCrafter | High-Res Upgrade Kit | **£99** (£30 w/o objective) | 40×/160 mm Plan objective, Ø12.7 f = 50 mm achromat, printed optics module + cover | — |
| TauLab (UK/EU) | Sangaboard v5 | **£28** | | |
| TauLab | Illumination kit / bag of bits / tube lens / geared stepper / O-ring / condenser lens / heatsink | £10 / £24 / £23 / £3.50 / £1 / £1 / £4.50 | | |

Other listed vendors without published prices: PSL3D (FR), Malkanicus (UK), MBOALAB (CM),
Fieldworkers (JP), IoWLabs (CL), Science Mate (AU), Bongo Tech (TZ), Pin29 (AR), PKI
Utveckling (SE), Africa OSH (GH).

**Derived single-unit v7 high-res motorised from TauLab parts (2026):** Sangaboard £28 + bag
of bits £24 + illumination £10 + 3 motors £10.50 + tube lens £23 + O-rings £3 + condenser £1
≈ £99.50; plus Pi 4/5 £50–80, Pi Cam v2 £25, PSU £10, objective £50–69, filament 255 g ≈ £6
→ **≈ £260–290 (≈ 305–340 €)**.

## D. Comparison for the thesis

| System | Camera / compute | Stage | Total |
|---|---|---|---|
| OFM v7 low-cost (Collins 2020) | webcam, no Pi | manual | $36 |
| OFM v7 high-res motorised (Collins 2020) | Pi Cam v2, Pi 3/4 | XYZ, Sangaboard | $251 |
| OFM v7 high-res motorised (vendor parts 2026) | Pi Cam v2, Pi 4/5 | XYZ, Sangaboard | ≈ 305–340 € |
| **Mesoscope, as built** (§A, objective owned) | IMX477 HQ, Pi 5 + Hailo-8 | Z only | ≈ 306 € |
| **Mesoscope + rail** (§A + B) | IMX477 HQ, Pi 5 + Hailo-8 | Z + X-rail, N chips | ≈ 443 € |
| Mesoscope + rail, objective at market value | | | ≈ 695 € |

Interpretation: the mesoscope replaces the XY flexure stage + Sangaboard (≈ 60 €) with a
linear rail (≈ 137 €) and adds an NPU (≈ 150 € incl. Pi 5 premium); the HQ camera + tube
lens optics cost about the same as the v7 high-res optics. Cost parity with a stock v7 is
therefore within ≈ 1.5×, while gaining multi-vessel scanning and on-device inference.

Sources: build.openflexure.org v7.0.0-beta1 BOM pages (high_res / low_cost), Delta Stage
BOM; Collins et al. 2020 SI (bioRxiv 10.1101/861856); MMC 2021 abstract; *The Pathologist*
2024-03; iorodeo.com products + blog 2024-03-20; labcrafter.co.uk; taulab.eu;
openflexure.org/about/vendors.

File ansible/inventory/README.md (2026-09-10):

# Ansible Inventory Configuration

This directory contains the Ansible inventory for mesoscope infrastructure (formerly "CELLAIR").

## Host Groups

### `rpi5` - Raspberry Pi 5 (Microscope)
- **Hostname:** `mesoscope.local` (or static IP)
- **User:** `lab`
- **Purpose:** OpenFlexure server, HQ Camera (IMX477), Hailo-8 inference

### `vps` - VPS (CVAT Annotation Server)
- **Hostname:** Your VPS IP or domain
- **User:** `root`
- **Purpose:** CVAT annotation tool for cell image labeling

## SSH Configuration

Ensure SSH keys are set up for both hosts:

```bash
# For Raspberry Pi
ssh-copy-id lab@mesoscope.local

# For VPS
ssh-copy-id root@your.vps.ip.address
```

## Testing Connection

```bash
# Test Pi connection
ansible rpi5 -m ping -i inventory/hosts.yml

# Test VPS connection
ansible vps -m ping -i inventory/hosts.yml
```

## Editing Inventory

Edit `hosts.yml` to update:
- IP addresses/hostnames
- SSH key paths
- CVAT credentials (in `group_vars/vps.yml`)

## Security Notes

1. **Never commit passwords** - Use Ansible Vault for production:
   ```bash
   ansible-vault encrypt group_vars/vps.yml
   ansible-playbook cvat.yml --ask-vault-pass
   ```

2. **Change default passwords** after deployment

3. **Use firewall** on VPS:
   ```bash
   ufw allow 22/tcp
   ufw allow 80/tcp   # Caddy ACME challenge
   ufw allow 443/tcp
   ufw enable
   ```

4. **SSH key management** - Each user manages their own keys; this repo only configures the `cvat` service user

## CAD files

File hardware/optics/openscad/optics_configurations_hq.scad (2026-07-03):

// Optics configurations for the mesoscope project
// Pi HQ Camera (IMX477) with 100mm, 125mm and 150mm achromatic doublet tube lenses
//
// Extends the upstream OpenFlexure optics_configurations.scad for the
// hq_camera branch. Three RMS configurations are provided:
//   - rms_f100d13_config: 100mm achromatic doublet, 12.7mm dia (f=100mm, ffd=TBD)
//   - rms_f125d13_config: 125mm achromatic doublet, 12.7mm dia (f=125mm, ffd=124.1mm)
//   - rms_f150d13_config: 150mm achromatic doublet, 12.7mm dia (f=150mm, ffd=148.8mm)
//
// All use picamera_hq as the default camera type and maintain the same
// lens diameter (12.7mm) and finite conjugate 160mm tube length as upstream.
//
// Lens specs (BK7+SF2, from taulab supplier via Filip, 2026-06-22):
//   100mm: Fb=TBD (ffd placeholder = 98.0mm — UPDATE when datasheet received)
//   125mm: Fb=124.1mm, T1=3mm, T2=1.3mm, R1=100.08mm, R2=-46.88mm, R3=-109.15mm, AR@400-700nm
//   150mm: Fb=148.8mm, T1=3mm, T2=1.3mm, R1=130.619mm, R2=-55.232mm, R3=-121.056mm, AR@400-700nm
//
// References:
//   - OPTICS_MODULE.md for optical calculations
//   - CORRESPONDENCE.md for OpenFlexure team confirmation (William, 2026-03-30)

use <./libdict.scad>  // resolves via symlink in upstream libs/

// 100mm tube lens configuration (achromatic doublet, 12.7mm diameter)
// BEST MATCH for IMX477 sensor (7.857mm diagonal): M=0.414, FN=18.98mm, ~95% fill
// tube_lens_ffd = TBD — placeholder 98.0mm used until datasheet confirmed.
// *** UPDATE tube_lens_ffd BEFORE PRINTING when lens datasheet is received ***
function rms_f100d13_config(camera_type = "picamera_hq", beamsplitter=false, parfocal_distance=45) = let(
    parfocal_distance_validated = (parfocal_distance == undef) ? 45 : parfocal_distance,
    lens_objective_distance = max(45 - parfocal_distance_validated, 0) + 8.5,
    config_dict = [["optics_type", "RMS"],
                   ["camera_type", camera_type],
                   ["tube_lens_ffd", 98.0],  // *** PLACEHOLDER — confirm from datasheet ***
                   ["tube_lens_f", 100],
                   ["tube_lens_r", 12.7/2+0.1],
                   ["objective_parfocal_distance", parfocal_distance_validated],
                   ["beamsplitter", beamsplitter],
                   ["gripper_t", 1],
                   ["is_finite_conjugate", true],
                   ["objective_mechanical_tube_length", 160],
                   ["lens_objective_distance", lens_objective_distance],
                   ["camera_rotation", 0],
                   ["beamsplitter_rotation", 0]]
) config_dict;

function rms_infinity_f100d13_config(camera_type = "picamera_hq", beamsplitter=false, parfocal_distance=undef) = let(
    finite_config = rms_f100d13_config(camera_type, beamsplitter, parfocal_distance=parfocal_distance),
    replacements = [["is_finite_conjugate", false]]
) replace_multiple_values(replacements, finite_config);

// 125mm tube lens configuration (achromatic doublet, 12.7mm diameter)
// For <=4x objectives, or where wider field of view is desired
// tube_lens_ffd = 124.1mm (confirmed by taulab supplier via Filip, 2026-06-22)
function rms_f125d13_config(camera_type = "picamera_hq", beamsplitter=false, parfocal_distance=45) = let(
    parfocal_distance_validated = (parfocal_distance == undef) ? 45 : parfocal_distance,
    lens_objective_distance = max(45 - parfocal_distance_validated, 0) + 8.5,
    config_dict = [["optics_type", "RMS"],
                   ["camera_type", camera_type],
                   ["tube_lens_ffd", 124.1],
                   ["tube_lens_f", 125],
                   ["tube_lens_r", 12.7/2+0.1],
                   ["objective_parfocal_distance", parfocal_distance_validated],
                   ["beamsplitter", beamsplitter],
                   ["gripper_t", 1],
                   ["is_finite_conjugate", true],
                   ["objective_mechanical_tube_length", 160],
                   ["lens_objective_distance", lens_objective_distance],
                   ["camera_rotation", 0],
                   ["beamsplitter_rotation", 0]]
) config_dict;

// 150mm tube lens configuration (achromatic doublet, 12.7mm diameter)
// For <=10x objectives (preferred per OPTICS_MODULE.md analysis)
// tube_lens_ffd = 148.8mm (confirmed by taulab supplier via Filip, 2026-06-22)
function rms_f150d13_config(camera_type = "picamera_hq", beamsplitter=false, parfocal_distance=45) = let(
    parfocal_distance_validated = (parfocal_distance == undef) ? 45 : parfocal_distance,
    lens_objective_distance = max(45 - parfocal_distance_validated, 0) + 8.5,
    config_dict = [["optics_type", "RMS"],
                   ["camera_type", camera_type],
                   ["tube_lens_ffd", 148.8],
                   ["tube_lens_f", 150],
                   ["tube_lens_r", 12.7/2+0.1],
                   ["objective_parfocal_distance", parfocal_distance_validated],
                   ["beamsplitter", beamsplitter],
                   ["gripper_t", 1],
                   ["is_finite_conjugate", true],
                   ["objective_mechanical_tube_length", 160],
                   ["lens_objective_distance", lens_objective_distance],
                   ["camera_rotation", 0],
                   ["beamsplitter_rotation", 0]]
) config_dict;

// Infinity conjugate variants
// Use with infinity-corrected objectives (marked with ∞ on the barrel)
function rms_infinity_f125d13_config(camera_type = "picamera_hq", beamsplitter=false, parfocal_distance=undef) = let(
    finite_config = rms_f125d13_config(camera_type, beamsplitter, parfocal_distance=parfocal_distance),
    replacements = [["is_finite_conjugate", false]]
) replace_multiple_values(replacements, finite_config);

function rms_infinity_f150d13_config(camera_type = "picamera_hq", beamsplitter=false, parfocal_distance=undef) = let(
    finite_config = rms_f150d13_config(camera_type, beamsplitter, parfocal_distance=parfocal_distance),
    replacements = [["is_finite_conjugate", false]]
) replace_multiple_values(replacements, finite_config);

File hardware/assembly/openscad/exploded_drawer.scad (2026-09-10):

// Mesoscope — exploded view of the electronics drawer + tech stack only
// ---------------------------------------------------------------------
// Renders just the pull-out electronics drawer and the boards it carries
// (Raspberry Pi 5 -> AI HAT+ (Hailo-8) -> Sangaboard) either assembled
// (explode = 0) or pulled apart along +z (explode = 1). This is a focused
// cut of exploded_view.scad::drawer_with_boards() with its own, larger board
// spacing and per-board labels.
//
// Copied into the upstream clone's rendering/ dir by build_exploded.sh so it
// can `use` the upstream render library (electronics_drawer_frame_xy etc.).
//
// Coordinate frame = drawer-local (board inset applied via
// electronics_drawer_board_inset()); z up.

use <../openscad/libs/utilities.scad>
use <../openscad/libs/microscope_parameters.scad>
use <../openscad/libs/lib_microscope_stand.scad>
use <librender/assembly_parameters.scad>
use <librender/render_utils.scad>
use <librender/render_settings.scad>
use <librender/electronics.scad>

$fn = 48;

// 0 = assembled, 1 = fully exploded (override with -D explode=0.5 etc.)
explode = 1;

// 1 = draw the text labels; 0 = geometry + guide line only.
show_labels = 1;

// ---- part sources (relative to upstream rendering/) ----
STL = "../../../hardware/stl/models/";
DRAWER_STL = str(STL, "electronics_drawer_mesoscope.stl");

params = render_params();

// Board heights inside the drawer (hardware/stand/openscad/microscope_stand_readme.md)
pi5_z    = 5.5;
aihat_z  = 18.4;
sanga_z  = 34.2;

// ---- explosion offsets along +z (scaled by `explode`) ----
drawer_slide = 90;   // mm the drawer is pulled out of the stand
ex_board     = 28;   // per-board separation when exploded (larger than the full-stack view for clarity)

function ez(v) = [0, 0, v * explode];

// ===================== PARTS =====================

module raspberry_pi5(){
    color("ForestGreen") cube([85, 56, 1.6]);
    color("#404040") translate([22, 22, 1.6]) cube([15, 15, 2.5]);  // BCM2712
    color("#303030") translate([70, 5, 1.6]) cube([14, 13, 15]);    // USB stack
    color("#303030") translate([70, 22, 1.6]) cube([14, 13, 15]);
    color("#303030") translate([70, 40, 1.6]) cube([14, 15, 13]);   // Ethernet
    color("#b0b0b0") translate([0, 3, 1.6]) cube([51, 5, 8.5]);     // 40-pin GPIO header
}

module ai_hat(){
    color("ForestGreen") cube([65, 56, 1.6]);
    color("#202020") translate([25, 20, 1.6]) cube([14, 14, 1.5]);  // Hailo-8
    color("black") translate([0, 3, 1.6]) cube([51, 5, 8.5]);       // 40-pin header
    color("#505050") translate([2, 40, 1.6]) cube([20, 12, 3]);     // PCIe FPC connector
}

module sangaboard(){
    color("DarkOliveGreen") cube([65, 57, 1.6]);
    color("#202020") translate([26, 24, 1.6]) cube([14, 14, 3]);    // MCU
    for (dx = [8, 24, 40]) color("#303030") translate([dx, 42, 1.6]) cube([12, 12, 12]); // ULN2003 driver blocks
}

// Guide line + labels live INSIDE the drawer frame so they share the boards'
// coordinate system (electronics_drawer_frame_xy applies a translate+rotate).
module guide_line(inset, labels=true){
    if (explode > 0){
        z1 = inset.z + sanga_z + 3 * ex_board * explode + 20;
        color("Gray", 0.5) translate([inset.x, inset.y, 0]) cylinder(d=0.6, h=z1);
        if (labels)
            for (t = [[ "drawer",           inset.z - 6],
                      [ "Raspberry Pi 5",    inset.z + pi5_z   + ez(ex_board)[2]],
                      [ "AI HAT+ (Hailo-8)", inset.z + aihat_z + ez(2 * ex_board)[2]],
                      [ "Sangaboard",        inset.z + sanga_z + ez(3 * ex_board)[2]]])
                color("DimGray") translate([inset.x + 120, inset.y, t[1]]) rotate([90, 0, 0])
                    linear_extrude(0.5) text(t[0], size=7, halign="left");
    }
}

module drawer_scene(labels=true){
    slide = drawer_slide * explode;
    electronics_drawer_frame_xy(params, slide_dist=slide){
        coloured_render(extras_colour()) import(DRAWER_STL, convexity=6);
        inset = electronics_drawer_board_inset();
        translate(inset + [0, 0, pi5_z]   + ez(ex_board))     raspberry_pi5();
        translate(inset + [0, 0, aihat_z] + ez(2 * ex_board)) ai_hat();
        translate(inset + [0, 0, sanga_z] + ez(3 * ex_board)) sangaboard();
        guide_line(inset, labels=labels);
    }
}

// ===================== ASSEMBLY =====================
drawer_scene(labels = show_labels > 0);

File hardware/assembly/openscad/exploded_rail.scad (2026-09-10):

// Mesoscope — exploded view of the RAIL stack (tilted microscope on X-rail)
// ---------------------------------------------------------------
// Re-uses the massing modules of hardware/mount/openscad/rail_mount_mesoscope.scad
// (via `use`, so its own assembly section is NOT emitted) and pulls the layers
// apart along +Z:
//   base plate -> 2040 beam -> MGN12 rail -> carriage -> adapter -> microscope
//   -> X drive (leadscrew, NEMA17, nut block) -> bridge -> bioreactor chips.
// Copied into the upstream rendering/ directory by build_exploded.sh; the
// `use` path below is relative to that location. The microscope STL path
// inside rail_mount_mesoscope.scad resolves relative to that file, so it
// still finds hardware/stl/models/complete_microscope_rms.stl.
//
// `use` does not export variables, so the few layout numbers needed here are
// MIRRORED from rail_mount_mesoscope.scad (keep in sync):
//   carriage_x = 0, n_reactors = 4, reactor_pitch = 80, margin = 100,
//   gp_t = 8, ext_h = 20, oa_h = 115, reactor_h = 40.

use <../../../hardware/mount/openscad/rail_mount_mesoscope.scad>

// 0 = assembled, 1 = fully exploded
explode = 1;

// --- mirrored layout parameters ---
carriage_x    = 0;
n_reactors    = 4;
reactor_pitch = 80;
margin        = 100;
gp_t          = 8;
oa_z          = 20 + 115;                       // ext_h + oa_h
reactor_h     = 40;
span          = (n_reactors - 1) * reactor_pitch;
rail_x0       = -margin;
rail_len      = span + 2 * margin;
ls_len        = rail_len - 20;

// explosion offsets (mm, scaled by `explode`)
ex_beam    = 25;
ex_rail    = 50;
ex_carr    = 75;
ex_adapter = 100;
ex_scope   = 140;
ex_drive   = 60;
ex_bridge  = 200;
ex_chips   = 240;

function ez(v) = [0, 0, v * explode];

base_plate();
translate(ez(ex_beam))    beam();
translate(ez(ex_rail))    mgn12_rail();
translate(ez(ex_carr))    mgn12_carriage(carriage_x);
translate(ez(ex_adapter)) carriage_adapter(carriage_x);
translate(ez(ex_scope)) {
    microscope(carriage_x);
    optical_axis_line(carriage_x);
}
translate(ez(ex_drive)) {
    leadscrew();
    nema17(rail_x0 + 10);
    coupler(rail_x0 + 10);
    end_bearing(rail_x0 + ls_len + 10);
    nut_block(carriage_x);
}
translate(ez(ex_bridge)) reactor_bridge();
translate(ez(ex_chips))  for (i = [0 : n_reactors - 1]) reactor(i * reactor_pitch);

if (explode > 0)
    color("Gray", 0.5) translate([carriage_x, 0, -gp_t])
        cylinder(d=1, h=oa_z + reactor_h + ex_chips * explode + gp_t);

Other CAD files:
hardware/stl/models/main_body_original.stl
hardware/stl/models/main_body_mesoscope.stl
hardware/stl/models/complete_microscope_rms.stl
hardware/stl/models/main_body.stl
hardware/stl/models/actuator_assembly_tools.stl
hardware/bioreactors/chip_senkrecht_mit_bodenplatte.stl
hardware/stl/models/gear_rad2.stl
hardware/stl/models/gear_rad1.stl
hardware/stl/models/electronics_drawer_mesoscope.stl
hardware/stl/models/bioreactor_rack_n3.stl
hardware/stl/models/optics_hq_150_rms_threaded.stl
hardware/stl/models/optics_hq_125_rms_threaded.stl
hardware/stl/models/microscope_stand_mesoscope.stl
hardware/stl/models/electronics_drawer_original.stl
hardware/stl/models/lens_tool.stl
hardware/stl/models/optics_hq_125_rms.stl
hardware/stl/models/condenser.stl
hardware/stl/models/cable_tidies.stl
hardware/assembly/openscad/exploded_view.scad
hardware/body/openscad/main_body_mesoscope.scad
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

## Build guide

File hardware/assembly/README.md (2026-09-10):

# Assembly / exploded views

Exploded-view ("Explosionsdarstellung") renders of the full mesoscope, for the thesis figures.

## Files

| File | What |
|---|---|
| `openscad/exploded_view.scad` | Upright microscope stack, exploded along the optical (Z) axis: stand → electronics drawer (Pi 5 + AI HAT+ + Sangaboard) → Z-only main body → Z actuator + 28BYJ-48 motor → HQ-camera optics module (125 mm tube lens) → objective → HQ camera → bioreactor chip → trans-illumination LED. |
| `openscad/exploded_rail.scad` | Rail-mount stack, exploded along Z: base plate → 2040 beam → MGN12 rail → carriage → adapter → tilted microscope → X drive → bridge → 4 chips. Reuses `hardware/mount/openscad/rail_mount_mesoscope.scad`. |
| `openscad/exploded_drawer.scad` | Electronics drawer + tech stack **only**, exploded along Z: pull-out drawer → Raspberry Pi 5 → AI HAT+ (Hailo-8) → Sangaboard. A focused cut of `exploded_view.scad::drawer_with_boards()` with wider board spacing and per-board labels. |
| `build_exploded.sh` | Copies the scene + stand overrides into the upstream clone and renders the PNGs. |
| `exploded_view*.png` / `exploded_view_assembled.png` / `exploded_rail.png` | Rendered outputs (1600×1200, preview render). **Not committed / not LFS-tracked** — regenerate with the script. The upright stack is rendered in four variants: `exploded_view.png` (front, labelled), `exploded_view_back.png` (opposite side, rot_z 35° → 215°, labels mirrored to read correctly), and `_nolabels` versions of each (`exploded_view_nolabels.png`, `exploded_view_back_nolabels.png`) with the annotations removed (guide line kept). |
| `exploded_drawer*.png` | Electronics-drawer-only outputs: `exploded_drawer.png` (labelled), `exploded_drawer_nolabels.png` (guide line only) and `exploded_drawer_assembled.png` (boards seated). The thesis uses `exploded_drawer_nolabels.png` (Fig. "electronics drawer"). |

## Rendering

```bash
./build_exploded.sh          # upright stack + electronics drawer: exploded + assembled
./build_exploded.sh rail     # also the rail stack
EXPLODE=0.5 ./build_exploded.sh   # partial explosion (0 = assembled, 1 = full)
```

Needs OpenSCAD ≥ 2021.01, the upstream `hq_camera` clone at `sources/openflexure-microscope`
(see root `CLAUDE.md`), and the STLs in `hardware/stl/models/` (`git lfs pull`). Override the
binary with `OPENSCAD=…` and the image size with `IMGSIZE=…`.

## Placeholders (not print geometry)

`exploded_view.scad` imports the real STLs for stand, drawer, main body and optics module, and
uses upstream library models for feet, gears, lead screw and the 28BYJ-48 motor. **Simplified
boxes/cylinders** stand in for: the Pi 5 / AI HAT+ / Sangaboard PCBs, the HQ camera (C-mount
barrel + PCB, from the mechanical drawing), the bioreactor chip (70×40×16 mm, 18×8 mm window),
and the LED light source. The objective is the upstream generic RMS model, not ZEISS geometry.
Explosion offsets are hand-set (see the `ex_*` constants); they are illustrative, not to scale.

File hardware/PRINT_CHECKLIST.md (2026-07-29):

# Mesoscope Print Checklist

## Print Settings (all parts)

| Setting | Value |
|---|---|
| Material | **PLA schwarz** (Streulicht — alle optischen Teile zwingend schwarz) |
| Layer height | **0.15 mm** (Optics-Modul); 0.20 mm (alle anderen) |
| Nozzle | 0.4 mm |
| Infill | 20–30% |
| Walls | 3 |
| Supports | As noted per part below |
| Build plate adhesion | Brim recommended for main_body |

## Parts List

### Structural — Must Print

| # | File | Size | Supports | Notes | Status |
|---|---|---|---|---|---|
| 1 | `main_body.stl` | 6.0M | Yes (built-in) | Core frame with flexure stage | ☐ |
| 2 | `optics_hq_150_rms.stl` | 2.0M | No | IMX477 HQ Camera, 150mm tube lens (<=10x) — C-mount seat ⌀32.6mm | ☐ |
| 3 | `optics_hq_125_rms.stl` | 1.9M | No | IMX477 HQ Camera, 125mm tube lens (<=4x only) — C-mount seat ⌀32.6mm | ☐ |

### Actuation — Must Print

| # | File | Size | Supports | Notes | Status |
|---|---|---|---|---|---|
| 4 | `large_gears.stl` | 1.2M | No | Z-axis actuation | ☐ |
| 5 | `small_gears.stl` | 813K | No | X/Y actuation | ☐ |

### Illumination — Must Print

| # | File | Size | Supports | Notes | Status |
|---|---|---|---|---|---|
| 6 | `condenser.stl` | 653K | No | LED condenser housing | ☐ |
| 7 | `condenser_lid.stl` | 348K | No | Condenser top cover | ☐ |
| 8 | `illumination_dovetail.stl` | 191K | No | Condenser mount | ☐ |
| 9 | `illumination_thumbscrew.stl` | 21K | No | Condenser adjustment | ☐ |

### Accessories — Must Print

| # | File | Size | Supports | Notes | Status |
|---|---|---|---|---|---|
| 10 | `feet.stl` | 554K | No | Rubber foot inserts | ☐ |
| 11 | `sample_clips.stl` | 180K | No | Slide retaining clips | ☐ |
| 12 | `cable_tidies.stl` | 487K | No | Cable management | ☐ |
| 13 | `microscope_stand_mesoscope.stl` | 288K | Yes | **Custom stand:** Pi5 + AI-HAT + Sangaboard stack (+13mm drawer height) | ☐ |

### Tools — Print Once

| # | File | Size | Supports | Notes | Status |
|---|---|---|---|---|---|
| 14 | `actuator_assembly_tools.stl` | 261K | No | For gear assembly | ☐ |
| 15 | `gear_tools.stl` | 171K | No | For gear assembly | ☐ |
| 16 | `lens_tool.stl` | 73K | No | For tube lens insertion | ☐ |

## Not Printing

- ~~`optics_picamera_2_rms_f50d13.stl`~~ — Pi Camera v2 mount, incompatible mit IMX477
- ~~`picamera_2_cover.stl`~~ — Pi Camera v2 cover, incompatible mit IMX477
- ~~`picamera_hq_cover.stl`~~ — bare-PCB cover, nicht benötigt: die HQ Camera behält ihr
  C-Mount-Gehäuse und sitzt per Flansch direkt im Optics-Modul (kein PCB freigelegt)

## Optics Module Choice

Use **one** of the two custom optics modules:

| Module | Tube lens | Use case | Parameter |
|---|---|---|---|
| `optics_hq_150_rms.stl` | 150mm achromatic doublet | <=10x objectives (preferred) | `rms_f150d13` |
| `optics_hq_125_rms.stl` | 125mm achromatic doublet | <=4x objectives, wider FOV | `rms_f125d13` |

Verify `tube_lens_ffd` against your lens datasheet before printing. See `OPTICS_MODULE.md` for details.

> **STLs bereits generiert** (2026-06-20) — `build_optics.sh` wurde ausgeführt, beide STLs
> liegen in `hardware/stl/models/`. Neu generieren nur nötig wenn `tube_lens_ffd` angepasst wird.

## Regenerating STLs

If parameters change, rebuild from OpenSCAD:

```bash
cd hardware/optics/openscad
./build_optics.sh        # Both configurations
./build_optics.sh 150    # 150mm only
```

Output: `hardware/stl/models/optics_hq_{125,150}_rms.stl`

## Post-Print Checklist

- [ ] All parts printed and cleaned (remove supports, brims)
- [ ] Test fit: optics module on main body dovetail
- [ ] Test fit: gears on actuator shafts
- [ ] Insert M2/M3 heat-set inserts where required
- [ ] Verify tube lens seats cleanly in optics module
- [ ] **Test fit HQ Camera C-mount housing into optics module seat (32 mm OD, 4 mm deep, ~0.3 mm clearance)** — should slide in concentrically
- [ ] Check IMX477 ribbon cable routing through main body

## Assembly References

- `hardware/optics/BUILD_GUIDE.md` — Optics module assembly instructions
- `hardware/optics/OPTICS_MODULE.md` — Optics design parameters and lens selection
- `docs/OPENFLEXURE_SUITE.md` — Full software/hardware inventory

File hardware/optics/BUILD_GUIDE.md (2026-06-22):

# OpenFlexure Microscope Build Guide -- HQ Camera (IMX477) Variant

This guide covers building the OpenFlexure microscope with a Pi HQ Camera (IMX477)
and a custom 125-150mm tube lens, adapted from the standard Pi Camera v2 build.

> **Prerequisite:** Read [`OPTICS_MODULE.md`](OPTICS_MODULE.md) before starting.
> The custom tube lens is **required** -- the standard 50mm tube lens wastes ~75% of the IMX477 sensor.

---

## 1. Order Components

See [`../../order_list.md`](../../order_list.md) and [`../../order_list_taulab.md`](../../order_list_taulab.md).

**Critical purchase:**
- Achromatic doublet, 12.7mm diameter, 125mm or 150mm focal length (available from taulab)
- Choose based on scraped objective: 150mm for ≤10x, 125mm for ≤4x

**From Taulab:**
- Sangaboard v5 + illumination kit + bag of bits + 3× 28BYJ-48 stepper motors

---

## 2. Verify Objective Type

Before generating the optics module STL, verify your scraped objective:

| Marking | Type | Compatible? |
|---|---|---|
| `160 / 0.17` or `160` | 160mm finite conjugate | Yes, directly |
| `∞ / 0.17` or `∞ / -` | Infinity corrected | Needs different optics module |
| No marking | Likely 160mm finite | Measure WD and confirm |

Also check the parfocal distance:
- 45mm = standard DIN (most common)
- 35mm = older standard

---

## 3. Generate Custom Optics Module STL

The standard OpenFlexure STL files are for the Pi Camera v2 with 50mm tube lens.
We need custom optics modules for the HQ Camera (IMX477) with 125mm and 150mm tube lenses.

Custom OpenSCAD configurations are provided in `../openscad/`:

| File | Purpose |
|---|---|
| `openscad/optics_configurations_hq.scad` | Tube lens configs (125mm and 150mm) |
| `openscad/rms_optics_module_hq.scad` | Main module with config dispatch |
| `openscad/build_optics.sh` | Build script for both STLs |
| `openscad/README.md` | Parameter reference and usage |

### 3.1 Clone OpenFlexure repo

```bash
cd /path/to/mesoscope/sources
git clone --branch hq_camera --single-branch \
  https://gitlab.com/openflexure/openflexure-microscope.git
cd openflexure-microscope
git lfs install && git lfs pull
```

The build script (`build_optics.sh`) copies the custom configs into the upstream repo automatically.

### 3.2 Available configurations

No manual editing required — all configs are in `optics_configurations_hq.scad`:

| OPTICS name | Tube lens | Conjugate | Use case |
|---|---|---|---|
| `rms_f125d13` | 125mm | Finite (160mm) | <=4x objectives |
| `rms_f150d13` | 150mm | Finite (160mm) | <=10x objectives (preferred) |
| `rms_infinity_f125d13` | 125mm | Infinity | Infinity-corrected objectives |
| `rms_infinity_f150d13` | 150mm | Infinity | Infinity-corrected objectives |

All configs default to `CAMERA = "picamera_hq"` (confirmed by OpenFlexure team, William Wadsworth, 2026-03-30).

> **Note on camera screw holes:** The generated STL has no screw holes at the
> camera end. This is intentional — the four No.2 self-tapping holes in the
> upstream design are for bare-PCB mounting. The mesoscope uses the HQ Camera
> intact with its C-mount body; the camera is retained by the 32.6 mm flange
> seat, not screws.

> **Note on C-mount opening:** The OpenFlexure `sequential_hull()` closes the
> underside of the optics module. `rms_optics_module_hq.scad` reopens it with
> an explicit `difference()` (module `optics_module_rms_cmount`). See
> `openscad/README.md` for details.

### 3.3 Build STLs

```bash
cd /path/to/mesoscope/hardware/optics/openscad

# Build both configurations:
./build_optics.sh

# Or build one at a time:
./build_optics.sh 125     # 125mm tube lens
./build_optics.sh 150     # 150mm tube lens
```

Output: `../stl/models/optics_hq_125_rms.stl` and `optics_hq_150_rms.stl`

> **Verify `tube_lens_ffd` values** (122.6mm for 125mm, 146.9mm for 150mm) against your
> lens datasheet before printing. Edit `optics_configurations_hq.scad` if needed.

---

## 4. 3D Print Settings

### Print all parts from `../stl/models/`:

| Setting | Value |
|---|---|
| Material | PLA or PETG |
| Layer height | 0.15-0.2mm |
| Infill | 20-30% |
| Nozzle | 0.4mm |
| Supports | As indicated per part (see OpenFlexure instructions) |

### Required STL files:

- `main_body.stl` -- Microscope body with flexure stage
- `optics_hq_125_rms.stl` -- **Custom** 125mm tube lens (generated in step 3)
- `optics_hq_150_rms.stl` -- **Custom** 150mm tube lens (generated in step 3)
- `large_gears.stl` + `small_gears.stl` -- Actuation gears
- `condenser.stl` + `condenser_lid.stl` -- Illumination
- `feet.stl` -- Foot pads
- `sample_clips.stl` -- Slide clips
- `cable_tidies.stl` -- Cable management

> **Note:** The `optics_picamera_2_rms_f50d13.stl` and `picamera_2_cover.stl` in
> `../stl/models/` are for the Pi Camera v2 build and should **not** be used.

---

## 5. Assembly Order

Follow the [OpenFlexure v7 assembly instructions](https://build.openflexure.org/openflexure-microscope/v7.0.0-beta5/),
with these adaptations:

1. **Tube lens insertion:** Insert the 125-150mm achromatic doublet (not the standard 50mm lens)
   into the custom optics module. The longer focal length means the lens sits closer to the
   objective end of the tube.

2. **C-mount camera mounting:** The HQ Camera C-mount threads into the `picamera_hq` optics module variant (confirmed by OpenFlexure team, William Wadsworth 2026-03-30).

3. **Ribbon cable:** Route the 200mm ribbon cable from the HQ Camera through the microscope
   body to the Raspberry Pi 5 CSI port.

4. **Condenser:** Standard PMMA condenser lens (13mm, 5mm focal) works with ≤10x objectives.

5. **Illumination LED:** Mount the illumination module below the condenser.

---

## 6. Software Configuration

The Ansible playbook deploys OpenFlexure Server v3 configured for the HQ Camera (IMX477):
`StreamingPiCamera2` with `camera_board: "picamera_hq"`.

```bash
cd /path/to/mesoscope/ansible
ansible-playbook site.yml
```

### Verify camera detection:
```bash
rpicam-hello --list-cameras
# Should show: imx477 ; 4056x3040 ; / 2028x1520 /
```

### Verify OpenFlexure:
```bash
curl -s http://localhost:5000/ | head -5
```

---

## 7. Motorised Stage (when Sangaboard arrives)

1. Wire Arduino Nano (or Sangaboard v5) with 3× 28BYJ-48 stepper motors
2. Flash Sangaboard firmware (see `../../ansible/roles/motor-controller/files/flash-sangaboard.sh`)
3. Update OpenFlexure config to use Sangaboard instead of DummyStage
4. Test stage control via OpenFlexure web UI

---

## Checklist

- [ ] Confirm objective type: **finite conjugate 160mm**
- [ ] Confirm parfocal distance: **45mm** (DIN standard)
- [ ] Order tube lens: **125mm or 150mm achromatic doublet** (12.7mm dia)
- [ ] Look up `tube_lens_ffd` from datasheet for chosen lens — verify values in `hardware/optics/openscad/optics_configurations_hq.scad`
- [ ] Clone OpenFlexure repo (`hq_camera` branch) and set up symlinks (see step 3.1)
- [ ] Run `./build_optics.sh` to generate STLs for both tube lens configurations
- [ ] Print custom optics modules (125mm and/or 150mm)
- [ ] Print remaining STL parts (main body, gears, condenser, feet, clips)
- [ ] Assemble microscope with HQ Camera + custom tube lens + scraped objective
- [ ] Run Ansible playbook for software
- [ ] Verify camera and OpenFlexure web UI
- [ ] Wire motor controller and verify stage control

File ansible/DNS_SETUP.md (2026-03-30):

# DNS Setup for CVAT

## Required DNS Records

Create these records in your domain registrar's DNS settings:

### For cvat.feigl.dev (Recommended)

| Type | Name | Value | TTL |
|---|---|---|-----|
| A | cvat | 152.53.16.72 | 3600 |
| AAAA | cvat | fe80::245d:87ff:fe01:ca04 | 3600 |

### For cvat.182bit.dev (Alternative)

| Type | Name | Value | TTL |
|---|---|---|-----|
| A | cvat | 152.53.16.72 | 3600 |
| AAAA | cvat | fe80::245d:87ff:fe01:ca04 | 3600 |

## Verification

After DNS propagation (5-60 minutes), verify:

```bash
# Check A record
dig cvat.feigl.dev +short
# Expected: 152.53.16.72

# Check AAAA record
dig cvat.feigl.dev AAAA +short
# Expected: fe80::245d:87ff:fe01:ca04

# Or use ping
ping cvat.feigl.dev
```

## Update Ansible Configuration

Once DNS is set, update `group_vars/vps.yml`:

```yaml
cvat_host: cvat.feigl.dev  # or cvat.182bit.dev
```

## HTTPS Setup (After CVAT Deployment)

Caddy automatically provisions HTTPS certificates once DNS is configured.

No manual setup required! Access CVAT at:

```
https://cvat.feigl.dev
```

Caddy handles:
- Let's Encrypt certificate provisioning
- Automatic renewal
- HTTP → HTTPS redirect

## Troubleshooting

**DNS not resolving:**
- Wait for propagation (up to 1 hour)
- Check DNS cache: `dig @8.8.8.8 cvat.feigl.dev`
- Verify record at registrar

**HTTPS not working:**
- Ensure port 80 and 443 are open on VPS firewall
- Check Caddy logs: `sudo journalctl -u caddy -f`
- Verify DNS resolves to correct IP

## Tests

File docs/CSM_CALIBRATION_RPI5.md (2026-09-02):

# Camera–Stage Mapping (CSM) Calibration on Pi 5 / HQ Camera

> **Status:** Working procedure captured 2026-08-25. Candidate for an upstream
> OpenFlexure PR (`v3` / `hq_camera` / Raspberry Pi 5 support).
>
> This documents why the stock `camera_stage_mapping.calibrate_xy` action fails
> intermittently on the Pi 5 + HQ Camera (IMX477, pisp ISP), the root causes we
> found, and a robust out-of-process calibration that succeeds reliably.

Camera–stage mapping produces the `image_to_stage_displacement` matrix that maps
image pixels ↔ stage steps. Smart/tiled scans need it to place adjacent tiles so
they overlap; a wrong matrix makes tiles non-overlapping and stitching fails with
`N image(s) are disconnected` (surfaces in the UI as the live-stitch "network
error").

---

## Symptoms

The built-in action (`POST /camera_stage_mapping/calibrate_xy`, or the "Calibrate"
button in the UI) fails **non-deterministically** with one of:

- `MappingError: The fit didn't look successful! The residuals of fit were too
  large.` — raised in `camera_stage_calibration_1d.py` when
  `fractional_error = residual / |Δ fit| > 0.1`.
- `no motion detected` — the initial `move_until_motion_detected` never crosses
  the detection threshold.

Re-running sometimes "works" and sometimes doesn't, on the **same** focused
sample — the tell-tale of a tracking/robustness problem, not a bad sample.

---

## Root causes

### A. FFT tracker decorrelates during the stock backlash ramp
`calibrate_backlash_1d` builds a `Tracker(..., method="fft")` (high-pass FFT
template + `displacement_from_fft_template`). FFT template matching is only
reliable to roughly **25 % of the field of view** (~77 px on the 308×410
downsampled frame). The routine then does `move_until_motion_detected` (threshold
= `max_safe_displacement × 0.2` ≈ 61.6 px) and a 15-step backwards / 15-step
forwards ramp. On lower-contrast or repetitive textures the **per-step
displacement drifts outside the reliable range**, the template decorrelates, the
tracked points scatter, the linear fit residual exceeds 10 % → `MappingError`.
Because it depends on where the ramp lands on the sample texture, it is
non-deterministic.

### B. Pi 5 returns **4-channel RGBA** downsampled arrays (Pi 5 / pisp specific)
On the Pi 5 pisp pipeline, `POST /camera/capture_downsampled_array` returns a
**308×410×4 (RGBA)** array, not RGB. Any consumer that assumes 3 channels — e.g.
`cv2.cvtColor(arr, cv2.COLOR_RGB2GRAY)` — corrupts the grayscale conversion and
feeds garbage to the tracker. Always slice `arr[..., :3]` before converting:

```python
a = np.array(output)
if a.ndim == 3:
    a = a[..., :3]          # drop alpha — Pi 5 pisp returns RGBA
gray = cv2.cvtColor(a.astype(np.uint8), cv2.COLOR_RGB2GRAY).astype(np.float32)
```

### C. Operational hazard: do not stop/starve the stream during CSM
`capture_downsampled_array` reads from the active MJPEG/lores stream. **Stopping
the stream** during a CSM operation, or **hammering** captures faster than the
pipeline delivers frames, can wedge the server: captures start returning empty /
`NaN` arrays and the stage stops responding to moves. Recovery is a service
restart:

```bash
sudo systemctl restart openflexure
```

Rules of thumb: keep the stream running throughout calibration; leave a short
settle (≥ 0.4 s) after each move before capturing; never call the stream
stop/start endpoints mid-calibration.

---

## Robust procedure (out-of-process, small-step)

Instead of the stock 15-step ramp, drive the stage in **small fixed steps** so
each incremental displacement stays well inside the reliable correlation range
(~12 px), track cumulative displacement with windowed **phase correlation**
(`cv2.phaseCorrelate` + a Hann window), and linear-fit cumulative pixels vs.
cumulative steps per axis. Combine the two axes with the **stock library**
function so the stored format matches the server exactly, then divide by the
downsampling factor and persist.

Reference implementation: `ansible/roles/openflexure/files/csm_calibrate_rpi5.py`.

```bash
# On the Pi, with a focused, textured sample under the objective and the
# camera stream running:
cd /opt/openflexure/venv/lib/python3.13/site-packages
/opt/openflexure/venv/bin/python3 \
  /home/lab/mesoscope/ansible/roles/openflexure/files/csm_calibrate_rpi5.py
```

It prints per-axis fit quality and writes the result to
`/tmp/csm_new_settings.json` **without** installing it. Sanity-check the output:

- `FIT_OK = True` (both axes `fractional_error < 0.1`; we saw ~1.6–1.7 %).
- `minResp` per axis ≳ 0.8 (phase-correlation confidence stayed high).
- Matrix magnitudes are physically sane and **near axis-aligned** for a
  non-rotated camera (small off-diagonals).

Install and reload:

```bash
DEST=/var/openflexure/settings/camera_stage_mapping/settings.json
sudo cp -a "$DEST" "$DEST.bak.$(date +%Y%m%d-%H%M%S)"     # back up first
sudo install -m 644 -o lab -g lab /tmp/csm_new_settings.json "$DEST"
sudo systemctl restart openflexure                        # server loads it on startup
```

Verify it went live:

```bash
curl -s localhost:5000/camera_stage_mapping/calibration_required          # -> false
curl -s localhost:5000/camera_stage_mapping/image_to_stage_displacement_matrix
```

---

## Persistence format

The server writes/reads `last_calibration` at
`/var/openflexure/settings/camera_stage_mapping/settings.json` and reloads it on
startup. Only these fields are consumed:

```json
{
  "last_calibration": {
    "camera_stage_mapping_calibration": {
      "image_to_stage_displacement": [[-19.80, 0.04], [-0.06, 19.26]]
    },
    "downsampled_image_resolution": [308, 410],
    "image_resolution": [616, 820],
    "downsampling": 2
  }
}
```

The stored matrix is in **full-resolution** pixels → steps: the library computes
it from the downsampled tracking frames, then divides by the downsampling factor
(2).

---

## Worked example (this machine)

| | stale / broken | new (small-step) |
|---|---|---|
| matrix | `[[13.2, -8.0], [-8.2, 12.7]]` | `[[-19.80, 0.04], [-0.06, 19.26]]` |
| character | large spurious **rotation** (off-diagonals ≈ −8) | near axis-aligned |
| X fit error | — | 1.7 % |
| Y fit error | — | 1.6 % |
| backlash (x, y) | — | 158 / 84 steps |

Ground-truth cross-check at the focused position: Y moves of +500 / +1000 / +2000
steps produced 12.7 / 24.6 / 48.7 px of pure-vertical displacement
(≈ 0.025 px/step), matching an independent open-loop ramp. The stale matrix's
rotation was the reason scan tiles did not overlap.

---

## Notes toward an upstream PR

Two independently useful fixes for `v3` on the Pi 5:

1. **RGBA handling** — anything consuming `capture_downsampled_array` (including
   the CSM tracker glue in `things/camera_stage_mapping.py`) should tolerate a
   4-channel array (`[..., :3]`). This is a plain Pi 5 / pisp correctness fix.
2. **Tracker robustness** — bounding per-step displacement (small-step ramp) or
   re-templating each step keeps FFT/phase correlation inside its reliable range
   and removes the non-deterministic `residuals ... too large` failure. This can
   be offered as an alternative calibration path without changing the stored
   format (we reuse `image_to_stage_displacement_from_1d`).

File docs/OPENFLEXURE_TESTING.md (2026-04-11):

# OpenFlexure Software Testing Guide

Step-by-step guide to get OpenFlexure Server running and verify camera control
with the Pi HQ Camera (IMX477).

## Prerequisites

- Raspberry Pi 5 with Pi OS Trixie (book), Python 3.13
- Pi HQ Camera (IMX477) connected via CSI ribbon cable
- AI HAT+ installed (optional for camera testing)
- Ansible playbook already run: `ansible-playbook site.yml`

## Step 1: Verify Camera Detection

```bash
# On the Pi:
rpicam-hello --list-cameras

# Expected output:
# Available cameras:
# 0 : imx477 [4056x3040] (/base/soc/i2c0mux/i2c@1/imx477@1a)

# If not detected:
# 1. Check ribbon cable is seated correctly (blue side facing Ethernet port)
# 2. Check camera_auto_detect=1 in /boot/firmware/config.txt
# 3. Reboot: sudo reboot
```

## Step 2: Test Camera with rpicam

```bash
# Quick test capture
rpicam-hello --timeout 5000

# Capture a still image
rpicam-still -o /tmp/test_capture.jpg

# Capture at different resolutions
rpicam-still -o /tmp/test_hires.jpg --width 4056 --height 3040
rpicam-still -o /tmp/test_preview.jpg --width 2028 --height 1520

# Capture a video
rpicam-vid -o /tmp/test_video.h264 -t 5000
```

## Step 3: Verify OpenFlexure Server

```bash
# Check service status
sudo systemctl status openflexure

# If not running, start it:
sudo systemctl start openflexure

# Check logs if there are errors:
sudo journalctl -u openflexure -f
```

### Common Issues

| Error | Cause | Fix |
|---|---|-----|
| `ModuleNotFoundError: openflexure_microscope_server` | Package not installed | `cd /opt/openflexure/server && /opt/openflexure/venv/bin/pip install -e ".[pi]"` |
| `Camera not found` | IMX477 not detected or config issue | Verify `rpicam-hello --list-cameras`, check config |
| `Address already in use` | Another process on port 5000 | `sudo lsof -i :5000` then kill or change port |
| Permission denied on `/var/openflexure/` | Wrong ownership | `sudo chown -R lab:lab /var/openflexure/` |

## Step 4: Access Web UI

Open in browser: **http://mesoscope.local:5000**

You should see the OpenFlexure Microscope web interface.

## Step 5: Verify Camera in OpenFlexure

### Via Web UI
1. Open http://mesoscope.local:5000
2. Click "Start Stream" — you should see a live camera feed
3. Click "Capture" — a still image should be saved

### Via API

```bash
# Check camera status
curl -s http://mesoscope.local:5000/api/v2/camera/ | python3 -m json.tool

# Capture an image via API
curl -o /tmp/ofm_capture.jpg http://mesoscope.local:5000/api/v2/camera/capture

# Start/stop stream
curl -X POST http://mesoscope.local:5000/api/v2/camera/stream/start
curl -X POST http://mesoscope.local:5000/api/v2/camera/stream/stop
```

## Step 6: Test picamera2 Directly (Debugging)

If OpenFlexure camera doesn't work, test picamera2 directly:

```python
# On the Pi, in the OpenFlexure venv:
/opt/openflexure/venv/bin/python3 << 'EOF'
from picamera2 import Picamera2

picam2 = Picamera2()
config = picam2.create_still_configuration(
    main={"size": (2028, 1520)}
)
picam2.configure(config)
picam2.start()
import time
time.sleep(1)
picam2.capture_file("/tmp/picam2_test.jpg")
picam2.stop()
print("Camera capture successful: /tmp/picam2_test.jpg")
EOF
```

## Step 7: Timelapse Capture (Data Collection)

```bash
# Capture 100 images at 60-second intervals via API
python3 model/scripts/data_collection/capture_timelapse.py \
  --output data/raw \
  --interval 60 \
  --count 100 \
  --base-url http://mesoscope.local:5000

# Or capture locally on the Pi:
python3 model/scripts/data_collection/capture_local.py \
  --output /tmp/timelapse \
  --interval 60 \
  --count 100 \
  --resolution 2028x1520
```

## Configuration File

The OpenFlexure configuration is at: `/var/openflexure/settings/ofm_config.json`

Current configuration (IMX477 HQ Camera):

```json
{
    "things": {
        "camera": {
            "class": "openflexure_microscope_server.things.camera.picamera:StreamingPiCamera2",
            "kwargs": {
                "camera_board": "picamera_hq"
            }
        },
        "stage": "openflexure_microscope_server.things.stage.dummy:DummyStage",
        "autofocus": "openflexure_microscope_server.things.autofocus:AutofocusThing",
        ...
    }
}
```

> **Stage:** Currently `DummyStage`. Once the Sangaboard is wired and flashed, switch to:
> `"openflexure_microscope_server.things.stage.sangaboard:SangaboardThing"`
> Update in `ansible/roles/openflexure/templates/ofm_config.json.j2` and redeploy.

## Redeploy After Config Changes

```bash
# From the Ansible control machine:
cd /path/to/mesoscope/ansible
ansible-playbook site.yml --tags openflexure

# Or on the Pi, just restart the service:
ssh lab@mesoscope.local 'sudo systemctl restart openflexure'
```

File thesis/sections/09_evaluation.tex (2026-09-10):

\section{Evaluation}
\label{sec:evaluation}

\subsection{Cost}
The primary non-functional requirement is a parts cost below \num{500}~EUR
(NFR1, RQ1). Table~\ref{tab:cost} places the mesoscope against the open
OpenFlexure reference builds and a commercial-vendor estimate. The imaging head
as built (kit of parts, reusing an owned ZEISS objective) is
$\approx\num{306}$~EUR; adding the linear-rail motion subsystem brings the full
system to $\approx\num{443}$~EUR, still within the \num{500}~EUR budget. If the
objective had to be bought new at market price the total would rise to
$\approx\num{695}$~EUR, which is the main sensitivity in the budget.

\begin{table}[!t]
  \centering
  \caption{Parts-cost comparison. Mesoscope figures are from
  \texttt{docs/BOM\_COSTS.md}; the objective is reused (owned), so the
  market-objective row is shown separately.}
  \label{tab:cost}
  \begin{tabular}{@{}lr@{}}
    \toprule
    Configuration & Cost \\
    \midrule
    OpenFlexure v7, low-cost        & $\approx\num{36}$~USD \\
    OpenFlexure v7, high-res motorised & $\approx\num{251}$~USD \\
    Commercial vendor kit (2026)    & $\approx\num{305}$--$\num{340}$~EUR \\
    \midrule
    Mesoscope, imaging head (objective owned) & $\approx\num{306}$~EUR \\
    Mesoscope, head + rail (objective owned)  & $\approx\num{443}$~EUR \\
    Mesoscope, head + rail + market objective & $\approx\num{695}$~EUR \\
    \bottomrule
  \end{tabular}
\end{table}

\subsection{Optical resolution}
The diffraction-limited lateral resolution of the $10\times/0.30$ objective is
$\approx\SI{1.1}{\micro\meter}$ (Eq.~\ref{eq:rayleigh},
Section~\ref{sec:optical}), and the IMX477 sampling Nyquist-samples this
resolution. \todo{report the measured resolution (e.g.\ USAF~1951 target or a
Siemens star) against the diffraction limit once the optics module is aligned
(milestone~M1).}

\subsection{Mechanical repeatability}
FR3 requires repeatable stops at each chip station. \todo{measure the rail
station-to-station repeatability and the focus reproducibility once the
all-Python GPIO stage drives the hardware (milestone~M2).}

\subsection{Detection accuracy and latency}
\todo{report detection accuracy on a held-out set and end-to-end on-device
latency per chip once the task-specific detector is trained and compiled to HEF
(Section~\ref{sec:edgeai}, milestone~M1).}

\subsection{Unattended operation}
FR6/NFR4 require unattended operation inside the incubator
(\SI{37}{\celsius}, high humidity). \todo{report a multi-hour or multi-day
unattended run (uptime, thermal behaviour, image yield) as the end-to-end
system validation.}

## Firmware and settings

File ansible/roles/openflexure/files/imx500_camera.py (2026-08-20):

"""OpenFlexure Microscope IMX500 AI Camera Thing.

This module provides an OpenFlexure-compatible camera Thing for the
Raspberry Pi AI Camera (IMX500). The IMX500 sensor has an on-chip NPU
that runs inference in parallel with image capture.

The IMX500 requires firmware upload before the sensor can operate.
This is handled by the picamera2.devices.IMX500 class, which must be
instantiated before Picamera2.

See repository root for licensing information.
"""

from __future__ import annotations

import logging
import time
from contextlib import contextmanager
from threading import RLock
from types import TracebackType
from typing import Any, Iterator, Literal, Mapping, Optional, Self

import numpy as np
from picamera2 import Picamera2
from picamera2.devices import IMX500
from picamera2.encoders import MJPEGEncoder
from picamera2.outputs import Output
from PIL import Image

import labthings_fastapi as lt
from labthings_fastapi.types.numpy import NDArray

from openflexure_microscope_server.things.camera import BaseCamera, downsample
from openflexure_microscope_server.ui import PropertyControl, property_control_for

LOGGER = logging.getLogger(__name__)

DEFAULT_MODEL = "/usr/share/imx500-models/imx500_network_mobilenet_v2.rpk"


class IMX500StreamOutput(Output):
    """An Output class that sends MJPEG frames to an MJPEGStream."""

    def __init__(self, stream: lt.outputs.MJPEGStream) -> None:
        """Create an output that puts frames in an MJPEGStream."""
        Output.__init__(self)
        self.stream = stream

    def outputframe(
        self,
        frame: bytes,
        _keyframe: Optional[bool] = True,
        _timestamp: Optional[int] = None,
        _packet: Any = None,
        _audio: bool = False,
    ) -> None:
        """Add a frame to the stream's ringbuffer."""
        self.stream.add_frame(frame)


class IMX500Camera(BaseCamera):
    """A Thing providing an OpenFlexure camera interface for the IMX500 AI Camera.

    The IMX500 sensor includes an on-chip NPU that runs neural network
    inference in parallel with normal image capture. This class handles
    both standard imaging and optional inference output extraction.

    Args:
        thing_server_interface: The LabThings server interface.
        model_path: Path to the .rpk model file for the IMX500 NPU.
            A model must be provided for the sensor to operate, even
            if inference results are not used.
        camera_num: Camera index (usually 0 for single-camera setups).
    """

    stream_active: bool = lt.property(default=False, readonly=True)
    """Whether the MJPEG stream is active."""

    stream_resolution: tuple[int, int] = lt.property(default=(820, 616))
    """Resolution to use for the main MJPEG stream."""

    mjpeg_bitrate: Optional[int] = lt.property(default=100000000)
    """Bitrate for MJPEG stream."""

    calibration_crop_fraction: float = lt.property(default=1.0, ge=0.1, le=1.0)
    """Central fraction of the frame used by `capture_downsampled_array`.

    `camera_stage_mapping` (CSM) uses `capture_downsampled_array` for its
    autofocus-tracker cross-correlation (both the "fft" and "direct"
    algorithms). Our lens/illumination setup vignettes the corners of the
    full frame, which can starve the correlation of usable signal and make
    `calibrate_xy`/`calibrate_1d` fail with "MappingError: ... but saw no
    motion" even though the stage is actually moving (see
    docs/BIOREACTOR_POSITION.md). Setting this below 1.0 (e.g. 0.6) crops to
    the central region before downsampling, discarding the dark edges, while
    leaving `capture_array`/live preview/normal snapshots untouched.
    """

    def __init__(
        self,
        thing_server_interface: lt.ThingServerInterface,
        model_path: str = DEFAULT_MODEL,
        camera_num: Optional[int] = None,
    ) -> None:
        """Initialise the IMX500 camera."""
        super().__init__(thing_server_interface)
        self._model_path = model_path
        self._requested_camera_num = camera_num
        self._imx500: Optional[IMX500] = None
        self._picamera: Optional[Picamera2] = None
        self._picamera_lock = RLock()

    def __enter__(self) -> Self:
        """Initialise hardware and start streaming."""
        super().__enter__()
        self._initialise_imx500()
        self.start_streaming()
        return self

    def __exit__(
        self,
        exc_type: type[BaseException],
        exc_value: Optional[BaseException],
        traceback: Optional[TracebackType],
    ) -> None:
        """Close hardware connections."""
        self.stop_streaming()
        if self._picamera is not None:
            with self._picamera_lock:
                self._picamera.close()
                del self._picamera
                self._picamera = None
        super().__exit__(exc_type, exc_value, traceback)

    def _initialise_imx500(self) -> None:
        """Upload firmware to the IMX500 and create the Picamera2 instance."""
        LOGGER.info("Initialising IMX500 with model: %s", self._model_path)
        self._imx500 = IMX500(self._model_path)

        cam_num = (
            self._requested_camera_num
            if self._requested_camera_num is not None
            else self._imx500.camera_num
        )

        LOGGER.info("Creating Picamera2 instance for camera %d", cam_num)
        with self._picamera_lock:
            if self._picamera is not None:
                self._picamera.close()
                del self._picamera
            self._picamera = Picamera2(camera_num=cam_num)

    @property
    def streaming(self) -> bool:
        """True if the camera is currently streaming."""
        return self._picamera is not None and self._picamera.started

    @contextmanager
    def _streaming_picamera(self, pause_stream: bool = False) -> Iterator[Picamera2]:
        """Lock access to picamera and return the underlying Picamera2 instance."""
        already_streaming = self.stream_active
        with self._picamera_lock:
            if pause_stream and already_streaming:
                self.stop_streaming(stop_web_stream=False)
            try:
                yield self._picamera
            finally:
                if pause_stream and already_streaming:
                    self.start_streaming()

    # -- Streaming --

    @lt.action
    def start_streaming(
        self,
        main_resolution: tuple[int, int] = (820, 616),
        buffer_count: int = 6,
    ) -> None:
        """Start the MJPEG stream."""
        with self._streaming_picamera() as picam:
            try:
                if picam.started:
                    picam.stop()
                    picam.stop_encoder()
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

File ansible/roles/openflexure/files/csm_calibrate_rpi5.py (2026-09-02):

#!/usr/bin/env python3
"""Robust camera-stage-mapping (CSM) calibration for Pi 5 / HQ Camera.

The stock ``camera_stage_mapping.calibrate_xy`` action fails non-deterministically
on the Pi 5 pisp pipeline (``MappingError: ... residuals of fit were too large``).
See ``docs/CSM_CALIBRATION_RPI5.md`` for the full analysis. In short:

  * the stock FFT tracker decorrelates during its 15-step backlash ramp when the
    per-step displacement drifts outside the reliable (~25 % FOV) range, and
  * ``capture_downsampled_array`` returns a 4-channel RGBA array on the Pi 5,
    which naive RGB->gray conversion corrupts.

This script instead drives the stage in small fixed steps (~12 px/increment),
tracks cumulative displacement with windowed phase correlation, linear-fits
pixels vs. steps per axis, and combines the two axes with the *stock* library
function so the persisted format matches the server exactly.

Run on the Pi with a focused, textured sample under the objective and the camera
stream running:

    cd /opt/openflexure/venv/lib/python3.13/site-packages
    /opt/openflexure/venv/bin/python3 csm_calibrate_rpi5.py

Prints per-axis fit quality and writes ``/tmp/csm_new_settings.json`` WITHOUT
installing it. Install/reload steps are in the doc.
"""
import json
import time
import urllib.request

import cv2
import numpy as np
from camera_stage_mapping.camera_stage_calibration_1d import (
    image_to_stage_displacement_from_1d,
)

BASE = "http://localhost:5000"
STEP = 500      # steps per increment (~12 px -> stays inside reliable range)
N_FWD = 6       # forward increments per axis (~72 px total)
SETTLE = 0.6    # seconds to wait after a move before capturing


def get(path, timeout=20):
    return json.load(urllib.request.urlopen(BASE + path, timeout=timeout))


def post(path, body=None, timeout=30):
    req = urllib.request.Request(
        BASE + path,
        data=json.dumps(body or {}).encode(),
        headers={"Content-Type": "application/json"},
        method="POST",
    )
    r = json.load(urllib.request.urlopen(req, timeout=timeout))
    if isinstance(r, dict) and r.get("href"):
        for _ in range(120):
            inv = json.load(urllib.request.urlopen(r["href"], timeout=timeout))
            if inv.get("status") not in ("pending", "running"):
                return inv
            time.sleep(0.12)
        return inv
    return r


def grab():
    out = post("/camera/capture_downsampled_array", {}).get("output")
    a = np.array(out)
    if a.ndim == 3:
        a = a[..., :3]          # drop alpha -- Pi 5 pisp returns RGBA
    return cv2.cvtColor(a.astype(np.uint8), cv2.COLOR_RGB2GRAY).astype(np.float32)


def getpos():
    p = get("/stage/position")
    return np.array([p["x"], p["y"], p["z"]], float)


def move(new, settle=SETTLE):
    d = np.array(new, float) - getpos()
    post("/stage/move_relative",
         {"x": int(round(d[0])), "y": int(round(d[1])), "z": int(round(d[2]))})
    for _ in range(150):
        if not get("/stage/moving"):
            break
        time.sleep(0.1)
    time.sleep(settle)


_win = {}


def shift(a, b):
    h, w = a.shape
    if (h, w) not in _win:
        _win[(h, w)] = cv2.createHanningWindow((w, h), cv2.CV_32F)
    (sx, sy), resp = cv2.phaseCorrelate(a, b, _win[(h, w)])
    return sx, sy, resp


def calibrate_axis(name, direction, start):
    d = np.array(direction, float)
    move(start)
    for _ in range(3):                       # seat backlash in + direction
        move(getpos() + d * STEP)
    ref = grab()
    steps, cdx, cdy, resps = [0.0], [0.0], [0.0], []
    ax = ay = 0.0
    for _ in range(N_FWD):
        move(getpos() + d * STEP)
        nx = grab()
        sx, sy, r = shift(ref, nx)
        ax += sx
        ay += sy
        resps.append(r)
        steps.append(steps[-1] + STEP)
        cdx.append(ax)
        cdy.append(ay)
        ref = nx
    steps, cdx, cdy = np.array(steps), np.array(cdx), np.array(cdy)
    A = np.vstack([steps, np.ones_like(steps)]).T
    mx, bx = np.linalg.lstsq(A, cdx, rcond=None)[0]
    my, by = np.linalg.lstsq(A, cdy, rcond=None)[0]
    resid = np.sqrt(np.sum((cdx - A @ [mx, bx]) ** 2 + (cdy - A @ [my, by]) ** 2))
    span = np.hypot(cdx[-1], cdy[-1])
    frac = resid / span if span else 1.0
    ppsv = np.array([mx, my])
    pps = float(np.hypot(mx, my))
    # backlash: reverse 1000 steps (~24 px, still reliable), deficit vs expected
    r0 = grab()
    move(getpos() - d * 1000)
    r1 = grab()
    rsx, rsy, _ = shift(r0, r1)
    backlash = max(0.0, (pps * 1000 - np.hypot(rsx, rsy)) / pps) if pps else 0.0
    move(start)
    print(f"  {name}: pps={pps:.4f}px/step vec={np.round(ppsv, 4).tolist()} "
          f"frac_err={frac:.4f} backlash={backlash:.0f}steps "
          f"minResp={min(resps):.2f} (travel {span:.1f}px/{steps[-1]:.0f}steps)",
          flush=True)
    return {
        "stage_direction": np.array(direction, float),
        "image_direction": (ppsv / pps).tolist() if pps else [0, 0],
        "pixels_per_step": pps,
        "pixels_per_step_vector": ppsv.tolist(),
        "backlash": float(backlash),
        "fractional_error": float(frac),
    }


def main():
    dsf = get("/camera/downsampled_array_factor")
    img_res = list(grab().shape[:2])
    print(f"downsampling_factor = {dsf}  downsampled_res = {img_res}", flush=True)

    start = getpos()
    cals = {}
    for name, direction in [("x", (1, 0, 0)), ("y", (0, 1, 0))]:
        print(f"\n=== Calibrating {name.upper()} axis ===", flush=True)
        cals[name] = calibrate_axis(name, direction, start)
    move(start)

    cal_xy = image_to_stage_displacement_from_1d([cals["x"], cals["y"]])
    M = np.array(cal_xy["image_to_stage_displacement"], float) / dsf
    print("\n=== RESULT ===", flush=True)
    print("image_to_stage_displacement (after /downsampling):", flush=True)
    for row in M:
        print("   ", np.round(row, 4).tolist(), flush=True)
    print("backlash_vector:", np.round(cal_xy["backlash_vector"], 1).tolist(),
          flush=True)

    data = {"last_calibration": {
        "camera_stage_mapping_calibration": {
            "image_to_stage_displacement": M.tolist()},
        "downsampled_image_resolution": img_res,
        "image_resolution": [int(r * dsf) for r in img_res],
        "downsampling": int(dsf)}}
    with open("/tmp/csm_new_settings.json", "w") as f:
        json.dump(data, f, indent=2)
    fe_ok = all(cals[a]["fractional_error"] < 0.1 for a in ("x", "y"))
    print("\nWrote /tmp/csm_new_settings.json (NOT installed).", flush=True)
    print("FIT_OK =", fe_ok, flush=True)


if __name__ == "__main__":
    main()

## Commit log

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2026-03-10 Fix Ansible playbook errors in openflexure and motor-controller roles
    - Use dynamic Python package path detection instead of hardcoded python3.13
    path in openflexure fallback template task
    - Fix udev reload handler using shell instead of command to support &&
    - Reset ansible_host to mesoscope.local
2026-03-30 docs: correct tube lens spec to 125-150mm range, add OpenFlexure CAD workflow
    Tube lens specification corrected from ~135mm (calculated optimum) to
    125-150mm (available distributor options) across all documentation.
    Hardware status updated: 10x objective and Pi HQ Camera marked acquired,
    stepper motors status aligned between Phase 5 and BOM.
    OpenFlexure team (William) confirmed the CAD workflow: use hq_camera
    branch with CAMERA="arducam_b0196" and adjust tube_lens_f/tube_lens_ffd
    in optics_configurations.scad. No custom camera module needed.
    Source: OpenFlexure support email (William, March 2026)
    Refs: https://openflexure.discourse.group/t/arducam-b0196-on-high-resolution-v7-microscope/239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
    [high_res_microscope_BOM.csv]
2026-03-30 docs: fix remaining 135mm refs in presentation and BOM, add CAD format assessment
    - Replace all orphaned 135mm tube lens references with 125-150mm range
    in presentation.md (Slides 4, 5, 5b, 5d, 7, backup) and BOM CSV
    - Update Slide 5b to mark original estimate as superseded by Slide 5c
    - Update Slide 5d optical equations to show both 125mm and 150mm cases
    - Add Slide 5e: CAD format assessment (OpenSCAD vs commercial CAD),
    tagged priority:lowest — porting not recommended; upstream uses OpenSCAD
    exclusively and our modifications are 2 config parameters
    - Fix formula shorthand in OPTICS_MODULE.md line 106: f/(f-|p|) -> f/(f+|p|)
    [high_res_microscope_BOM.csv]
2026-03-30 style: apply University of Salzburg corporate design to Beamer presentation
    - Replace blue palette with PLUS green (#115740) and grey (#9C9C9C)
    - Add header: logo + 'University of Salzburg' left, author + date right,
    separated by green rule
    - Add footer: page x/y left, frame subtitle right, separated by green rule
    - Author set to Florian Feigl with short form for header
    - Standard LaTeX (Latin Modern) fonts retained
    - Update .gitignore to allow tracking of presentations/**/*.pdf
2026-03-31 Tighten logo-text gap and reduce text column height to lower wordmark
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2026-03-31 Revert to simple header layout, add \phantom spacer to force right padding
2026-03-31 Tighten header columns, style AG Lepperdinger like wordmark (ag grey, lepperdinger green bold)
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2026-03-31 Revert to working version: use \paperwidth, phantom spacer, add 0.1em left padding
2026-04-11 refactor: migrate to IMX477-only architecture and fix OpenFlexure v3 config
    - Replace IMX500 with IMX477 (HQ Camera) as sole camera throughout
    - Fix ofm_config.json.j2: correct class StreamingPiCamera2 + camera_board picamera_hq
    (verified against v3 source; previous PiCamera2Thing was non-existent)
    - Align config structure with v3 format (application_config block, data_folder)
    - Drop imx500-all package from ai-hat role; remove IMX500 deploy task
    - Fix vps.yml hardcoded passwords -> vault_* references; update .gitignore
    - Add BUILD_GUIDE.md, WIRING_GUIDE.md, CORRESPONDENCE.md (incl. William's email notes)
    - Add docs/OPENFLEXURE_TESTING.md: step-by-step camera bring-up guide
    - Add model/requ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
    [high_res_microscope_BOM.csv]
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2026-04-21 fix: add SupplementaryGroups to openflexure service for camera access
    systemd does not inherit user groups by default; the service needs
    explicit video and render group membership to access /dev/video*
    and /dev/media* devices for picamera2.
2026-04-22 fix: Pi 5 pisp ISP compatibility, pipewire masking, NOPASSWD sudo
    - Rewrite patch_rpi5_pisp.sh with complete patches for OpenFlexure
    v3 on Pi 5: load system pisp tuning for property reads, skip
    passing it to Picamera2 so it uses its built-in default, handle
    ServerNotRunningError during init, remove readonly from tuning
    setting, clean up persisted empty tuning from settings.json
    - Add pipewire/wireplumber masking to base role to prevent camera
    device conflicts (pipewire holds /dev/media* devices)
    - Add NOPASSWD sudoers entry for app user in base role
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2026-05-03 docs: update roadmap with Pi 5 fixes, print progress, and deployment notes
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2026-06-22 feat(optics): fix C-mount opening in HQ camera optics module STLs
    - Fix sequential_hull() closing the C-mount bore in optics_module_rms():
    add optics_module_rms_cmount() wrapper with explicit post-hull difference()
    cutting flange seat (⌀32.6mm × 4mm) and clear optical bore (⌀26mm)
    - Regenerate optics_hq_150_rms.stl and optics_hq_125_rms.stl
    - Document fix in openscad/README.md and BUILD_GUIDE.md
    - Update OPTICS_MODULE.md checklist (linsen erhalten, STLs generiert)
    - Add system architecture diagram (Schiene + Bioreaktoren) to README.md
    - Fix 26 TOPS (was incorrectly 27 TOPS) across all docs
    - Update tube lens BOM status to Acquired
    [optics_hq_125_rms.stl, optics_hq_150_rms.stl, picamera_hq_cmount.scad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]
2026-06-22 fix(optics): update tube_lens_ffd with confirmed values from taulab
    125mm lens: ffd 122.6 -> 124.1mm
    150mm lens: ffd 146.9 -> 148.8mm
    Source: taulab supplier specs via Filip (2026-06-22)
    Lens material: BK7+SF2, AR coated 400-700nm
    Regenerate both STLs with corrected values.
    [optics_configurations_hq.scad, optics_hq_125_rms.stl, optics_hq_150_rms.stl]
2026-06-26 fix(optics): add bridging cone to structurally connect C-mount seat ring
    The sequential_hull leaves a ~5mm unsupported gap between the hull body
    bottom and the seat ring. Add a solid bridging cylinder with a conical
    inner bore (tapers from 26mm clear bore at top to 32.6mm seat at bottom)
    to fill the gap. 256 triangles verified spanning the full gap zone.
    Regenerate both STLs.
    [optics_hq_125_rms.stl, optics_hq_150_rms.stl, rms_optics_module_hq.scad]
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2026-07-03 feat(hq-cam): HQ Camera C-mount optics module and RPi5/AI-HAT drawer
    Hardware changes:
    - picamera_hq_cmount.scad: two-step C-mount bore + flange with 4x retention towers
    - rms_optics_module_hq.scad: updated constants for ring recess geometry
    - optics_configurations_hq.scad: corrected IMX477 sensor diagonal (7.857mm),
    added 100mm placeholder config and 125/150mm configs
    - build_optics.sh: add 125-upstream build path via standard OFM pipeline
    - OPTICS_MODULE.md: corrected sensor size, updated optical calculations
    STLs:
    - optics_hq_125_rms_upstream.stl: 125mm tube lens, upstream pipeline
    - optics_hq_150_rms.stl: rebuilt with updated geometry
    Submodule resources/openflexure-microscope update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
    [optics_configurations_hq.scad, optics_hq_125_rms_upstream.stl, optics_hq_150_rms.stl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]
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2026-07-29 feat(stand): add Pi5+AI-HAT+Sangaboard microscope stand variant
    Upstream microscope_stand.scad is designed for Pi4+Sangaboard (47mm
    drawer, 18mm sanga height). Our stack needs:
    - electronics_drawer_h: 47mm → 60mm
    - sanga_stand_height: 18mm → 29.5mm (AI-HAT adds one floor)
    - pi_version=5: micro-HDMI cutouts, no headphone jack
    - ai_hat_lugs: intermediate support posts at Z=14mm
    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
    [lib_microscope_stand_mesoscope.scad, microscope_stand_mesoscope.scad, microscope_stand_mesoscope.stl]
2026-07-29 feat(stand): add electronics drawer for Pi5+AI-HAT+Sangaboard
    - electronics_drawer_mesoscope.scad: entry point with pi_version=5,
    sanga_version=ai_hat_stack
    - build_stand.sh: also builds electronics_drawer variant
    - STL: hardware/stl/models/electronics_drawer_mesoscope.stl (634K)
    [electronics_drawer_mesoscope.scad, electronics_drawer_mesoscope.stl]
2026-07-29 fix(stand): remove unnecessary micro-HDMI cutout, disable STL LFS
    Pi5 front connectors: removed redundant micro-HDMI cutout at Y=35.5.
    micro-HDMI connectors sit near the board edge (Y=6-7) and are already
    covered by the USB cutout at Y=9.
    Also disable LFS for *.stl since git-lfs is not available on this
    machine.
    [actuator_assembly_tools.stl, cable_tidies.stl, condenser.stl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]
2026-07-29 fix: re-enable LFS for *.stl (git-lfs now installed)
2026-07-30 hardware: electronics drawer Pi5+AI-HAT+Sangaboard support
    - lib_microscope_stand_mesoscope.scad: two-level mounting for ai_hat_stack
    - sanga_lugs() unchanged at Z=20.5mm for AI HAT+
    - two additional no2_selftap_lug at Z=35.7mm for Sangaboard
    - sanga_connector_holes shifted +15.2mm for Sangaboard USB-C
    - sanga_lugs/sanga_connector_holes: ai_hat_stack uses Pi hole positions
    - build_stand.sh: fix output path (hardware/stl/models)
    - microscope_stand_readme.md: full documentation with measurements,
    approach, open issues (Pi5 Ethernet/USB-A positions unverified)
    - STLs rebuilt
    [electronics_drawer_mesoscope.stl, electronics_drawer_original.stl, lib_microscope_stand_mesoscope.scad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]
2026-07-30 hardware: Pi5 front connector positions from official mechanical drawing
    pi_front_connectors(pi_version=5): use Y-centres from
    datasheets.raspberrypi.com/rpi5/raspberry-pi-5-mechanical-drawing.pdf
    - Ethernet: Y=47mm (was 45.75, Pi4 value)
    - USB 2.0: Y=29.1mm (was 27)
    - USB 3.0: Y=10.2mm (was 9)
    Side connector X positions (11.2/25.8/39.2) confirmed unchanged vs Pi4.
    [electronics_drawer_mesoscope.stl, lib_microscope_stand_mesoscope.scad, microscope_stand_mesoscope.stl]
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2026-08-03 docs: mark camera black frame issue resolved, document manual exposure fix
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2026-08-17 Revert "docs: document Sangaboard v0.5 HAT GPIO UART setup; wire real stage into ansible"
    This reverts commit 5d8caf3302d2404ca15e578b42fe469624f2079e.
2026-08-20 feat: crop CSM tracker capture to avoid vignetted corners
    camera_stage_mapping's calibrate_xy/calibrate_1d fails with
    "MappingError: ... but saw no motion" even though the stage moves.
    Root cause suspected by community: dark/vignetted corners of the
    full frame reduce contrast for the FFT/direct cross-correlation
    tracker.
    Add a calibration_crop_fraction property to IMX500Camera and
    override capture_downsampled_array to crop to the central fraction
    before downsampling. Only affects the CSM tracker path; capture_array,
    live preview, and normal snapshots are unaffected.
    Document the new option and how to test it in BIOREACTOR_POSITION.md.
    [imx500_camera.py]
2026-08-21 feat: printed threaded C-mount option + slicer output refresh, presentation redesign
    - Add THREADED_CAMERA_MOUNT option to picamera_hq_cmount.scad/rms_optics_module_hq.scad:
    a printed 1"-32 UN male thread that screws directly into the HQ Camera
    C-CS adapter, as an alternative to the existing RMS-upstream mount.
    - build_optics.sh: add build_stl_threaded() target; replace hardcoded
    /home/feivel/dev/mesoscope paths with $HOME/relative path resolution
    so the script works across machines.
    - Regenerate STL/gcode outputs: new threaded C-mount STL/gcode, updated
    electronics drawer gcode; drop stale gcode for parts no longer built
    from this script (condenser lid, microscope stand, RMS-ups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
    [optics_hq_125_rms_threaded.stl, optics_hq_150_rms_threaded.stl, picamera_hq_cmount.scad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]
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2026-08-24 docs: add CLAUDE.md guidance for Claude Code
    Document the repo as a hardware + infrastructure project (Ansible
    deploys, OpenSCAD CAD, no app source), the two deployment targets
    (Pi 5 microscope vs. VPS/CVAT), common commands, and the cross-file
    Pi 5 workarounds encoded in the Ansible roles.
2026-08-24 hardware: add bioreactor chip STL for RAILS rack design
    Drop the user-provided bioreactor (chip senkrecht mit Bodenplatte) into
    hardware/bioreactors/ per the drop path in docs/RAIL_MOUNT_CONCEPT.md §6.
    Provides outer geometry / optical window reference for the parametric
    bioreactor rack. Stored via Git LFS.
    [chip_senkrecht_mit_bodenplatte.stl]
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2026-08-25 mount: wire real bioreactor chip geometry into rail-mount draft
    Use the team's bioreactor STL (hardware/bioreactors/) and wire its measured
    chip body into the schematic rail-mount SCAD. Base plate (Bodenplatte) removed
    for the calculations per instruction; chip body = 70 x 40 x 16 mm, optical
    window 18 x 8 mm centered on the microscope-facing face with 4 fluidic ports.
    Reactor row now uses real dims (series pitch still an assumption, 80 mm).
    Refresh both previews and update the concept doc (blocker cleared).
    [rail_mount_mesoscope.scad]
2026-08-25 mount: correct concept — moving microscope on shared Grundplatte, fixed reactor row
    Fix the mechanical concept per feedback: the rail is bound UNDER the mesoscope
    so the microscope travels along a STATIONARY row of bioreactors. Rail (with the
    moving microscope) and a fixed reactor stand both mount to one shared base plate
    (Grundplatte), keeping optical-axis-to-sample distance fixed by construction.
    SCAD: replace the cantilevered rack() with base_plate() (shared foundation) and
    reactor_stand() (fixed shelf + back wall on the Grundplatte). Reactors no longer
    ride the drive beam. Refresh both previews and rewrite the concept doc (§1 goal,
    §3 shared-Grundplatte principle + diagram, §4 foun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
    [rail_mount_mesoscope.scad]
2026-08-25 mount: embed real assembled mesoscope model in the rail-mount view
    Replace the placeholder envelope box with the actual OpenFlexure/mesoscope
    geometry. Render upstream rendering/complete_microscope_rms.scad to
    hardware/stl/models/complete_microscope_rms.stl (LFS) and import() it into
    rail_mount_mesoscope.scad behind a real_model flag.
    The upstream RMS render applies rotate([-90,0,0]) → in the STL the optical axis
    is the line x=0,z=0 pointing +Y (objective toward the reactors) and the sample
    plane is at y=sample_z=75, so no extra rotation is needed: only a translate onto
    the carriage (oa_z≈135 so the resting face lands on the adapter). Register the
    reactor optical window at the microscop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
    [complete_microscope_rms.stl, rail_mount_mesoscope.scad]
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2026-08-25 fix: remove sample clips from embedded model, de-collide bridge traverse
    Microscope STL re-rendered without sample clips (new noclips render
    variant) so the chip sits where the clips were, like a slide against the
    stage. Traverse board slimmed to 24 mm and moved behind y=80: at board
    height the microscope reaches only y=78 (measured from the STL), so the
    moving body clears the fixed bridge. Cutouts are now front-open notches.
    Documented the quantified condenser conflict (2.5 mm slide gap vs 16 mm
    chip) as the required stock-geometry modification.
    [complete_microscope_rms.stl, complete_microscope_rms_noclips.scad, rail_mount_mesoscope.scad]
2026-08-25 fix: correct 75mm registration error, remove illumination arm, 10mm working gap
    The render scene includes the stand, which raises the frame 75 mm: the
    sample plane sits at model y=150, not 75 — this wrong registration caused
    both earlier "too close"/clipping rounds. New model variant
    complete_microscope_rms_noclips_noillum.scad drops the whole illumination
    assembly (dovetail, condenser, wiring) per decision — a custom light
    source behind the chips comes later. Placement now derives from the
    measured objective tip (model y=146.65): model_dy = (75-10)-146.65 puts
    the tip at world y=65 with an exact 10 mm gap to the chip window at y=75;
    the entire microscope stays at y<=65, clearing chips,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
    [complete_microscope_rms.stl, complete_microscope_rms_noclips.scad, complete_microscope_rms_noclips_noillum.scad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]
2026-08-25 docs: robust CSM calibration for Pi 5 / HQ Camera
    The stock camera_stage_mapping.calibrate_xy fails non-deterministically on
    the Pi 5 pisp pipeline ("residuals of fit were too large"). Document the two
    root causes (FFT tracker decorrelating during the 15-step backlash ramp, and
    capture_downsampled_array returning 4-channel RGBA) plus the stream-wedge
    operational hazard, and add a reusable small-step phase-correlation
    calibration script that reuses the stock combine function so the persisted
    format matches the server.
    Candidate for an upstream OpenFlexure PR (v3 / hq_camera / Pi 5).
    [csm_calibrate_rpi5.py]
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2026-08-25 openflexure: vertically flip camera image on Pi 5
    Optical path delivers a top/bottom-inverted image and OpenFlexure v3
    exposes no orientation setting, so inject picamera2 Transform(vflip=1)
    into the streaming and still-capture configs via the pisp patch script.
    Idempotent; applies at the ISP level so preview and captures match.
    Verified live on the microscope.
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2026-09-10 thesis: IEEEtran master's thesis scaffold with existing content
    LaTeX draft (IEEEtran journal) covering intro, background, requirements,
    optical, mechanical, electronics, software, edge-AI and cost analysis;
    future-experiment results are marked with red [TODO] placeholders. Includes
    references.bib, a Makefile (pdflatex + bibtex) and a missing-figure fallback so
    the build never hard-fails on uncommitted render PNGs. Adds the supporting
    docs (outline, parameter gaps, roadmap, BOM costs).
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2026-09-10 hardware: fix Pi 5 drawer cutouts to Pi3-style Ethernet/USB layout
    Pi 5 swapped Ethernet and USB back to the Pi3 arrangement (Ethernet at the far
    end, USB stacks next to the GPIO edge). Reposition the three front-edge drawer
    cutouts to the Pi3 pattern with Pi5 magnitudes and re-render the drawer STL.
    [electronics_drawer_mesoscope.stl, lib_microscope_stand_mesoscope.scad]
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2026-09-10 docs: align stage architecture on the 2026-09-03 hybrid decision
    Resolve the Sangaboard-vs-all-Python-GPIO contradiction in favour of the
    committed 2026-09-03 hybrid: the Sangaboard keeps focus (28BYJ-48/ULN2003)
    and the illumination LED, while a standalone TMC2209 at GPIO drives the rail.
    Drop the milestone-M2 TODO in the thesis electronics section and update the
    RAIL_MOUNT_CONCEPT status banner and §8 handoff steps to match.
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2026-10-07 docs: adopt mirror-based ModLight fibre illumination for calcification imaging
    Fix the trans-illumination decision for the rail-mounted IDANA head: a single
    fibre-coupled, mirror-based ModLight source (Gibson et al. 2023) on the moving
    head rather than fixed per-station panels. Green (~525-530 nm) for Alizarin
    Red S contrast, white for von Kossa, NIR to penetrate the 16 mm chip and image
    birefringent hydroxyapatite nodules. Sangaboard PWM drives the single active
    channel; the ModLight LED controller stays a documented multi-channel fallback.
    Threads the calcification rationale through background -> optical design,
    documents the manual-mirror (one-channel-per-scan) caveat, and removes the
    st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
2026-10-08 fix(gears): correct Rad 1 bore to measured existing gear (Ø17.95, Z=13)
    The bore was modelled with radius values mistaken for diameters (Ø36),
    so Rad 1 would not grip the real Ø17.95 / 13-tooth gear. Set BORE_TIP,
    BORE_ROOT and Z_BORE from measurements and shrink BORE_VR to suit the
    shallower teeth; regenerate both STLs.
2026-10-08 fix(gears): restore Rad1 bore teeth and add meshing backlash
    Revert BORE_VR to 1.30 so the 13 keyed bore teeth are actually cut
    (0.40 collapsed the valley notches and smoothed the bore). Set
    BACKLASH=0.15 so the printed outer mesh turns freely.
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2026-10-26 feat(rails): rework bioreactor bridge to metal-spine hanging rack
    Rewrite bioreactor_rack.scad from the one-piece hanging board to a
    modular, printable design: one segment per station threaded onto two
    steel spine rods anchored in the end pillars. The rods carry the span
    load (no printed inter-segment joints — at pitch 75 the ~4 mm gap
    between chip holes leaves no room for a robust half-lap/pin/screw).
    - Kranz now rests flat on the segment top (recess removed; a flange on
    a flat face seats evenly): board_top = chip_top_z - kranz_h.
    - Subdivide into N per-station segments (~75 mm each) for the print bed.
    - Two Ø6 steel rods (NON-PRINT) run through the front/back Y-rails;
    each segment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
2026-10-27 revert(body): drop M3 nut traps at Z-motor cover screws
    The captive-nut pockets (5d4f0b1) cut a soft-edged triangular slot into
    the Z-motor cover screw holes. Revert to the stock upstream cylindrical
    motor_lugs seat (round m4_selftap_hole), matching the original body.
    Rebuilt main_body_mesoscope.stl accordingly.
2026-10-28 feat(body): add captive M3 nut traps at Z-motor cover screws
    Reinstate the captive M3 nuts at the two Z-motor mounting screws so the
    stepper bolts on with nuts instead of self-tapping into plastic, matching
    the genuine original body.
    The upstream motor_lugs only cut a Ø4.6 self-tap trylinder (triangular) at
    each screw. That hole is wider than an M3 clearance, so the first attempt
    (5d4f0b1, reverted) left soft triangular lobes around the screw. Instead
    plug the trylinder solid (z_motor_lug_plugs, r=2.6 inside the r=4 boss)
    and re-cut the clean Ø3.45 (actuator_shaft_radius 1.725) M3 clearance plus
    the hex pocket from the whole assembled body.
    Verified screw-local: round Ø3.45 clearance at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
2026-10-29 feat(rails): one-piece bridge + 2 towers; modern deck; turn drawer 180°
    Replace the earlier 3-segment half-lap spliced bridge with a simpler
    printable set: one continuous bridge board (N=3, ~280 mm < 300 mm bed)
    resting on two separate end towers, bolted 2x M3 per end. Towers bolt to
    the Grundplatte (M5) and sit just outside the end chips, keeping the space
    below the hanging chips free for the moving imaging head.
    - bioreactor_bridge_split.scad: rewritten as 1 bridge + 2 towers (3 print
    parts), parametric in N/pitch, asserts guard bed fit and tower/chip
    clearance.
    - build_bridge_split.sh: render bridge + tower STLs + exploded preview PNG.
    - presentation.tex: light/modern theme (blue ID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
2026-10-29 feat(bioreactors): optimized chip — base plate removed, anti-warp lip
    Add chip_senkrecht_optimiert (SCAD + binary STL) derived from the delivered
    mesh chip_senkrecht_mit_bodenplatte.stl. The full 140x100 mm back plate
    (present only as print warp control) is cut away via an intersection against
    the chip-body footprint, keeping the 70x16x40 mm body and all fluidics
    (optical window, 4 ports, internal chamber) 1:1 and watertight. A slim 3 mm
    foot lip around the bed-contact face is kept as reduced warp control.
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2026-11-03 feat(rails): bridge mounts on tower pins instead of M3 bolts
    Towers get M3-sized locating pins where the M3 holes used to be; the
    bridge keeps its unchanged M3 clearance holes so the existing bridge
    part stays reusable. Board halved to 4 mm. Regenerated N=3 STLs + preview.
2026-11-03 docs(presentation): simplify upcoming-challenges slide, crop exploded view
    Rewrite the challenge bullets in plainer language (90° tilt, FOV vs ROI,
    back-lighting, open mechanical details) and drop the motor/gear bullet.
    Swap in a cropped exploded view so it fills the slide width.
2026-11-03 docs: condense CLAUDE.md, trim redundancy and prose
    Collapse the intro, deduplicate the "needs upstream clone" note, and
    tighten the architecture bullets. All sections, commands and critical
    caveats (DKMS reboot, pisp patch, LFS, vault) retained.
